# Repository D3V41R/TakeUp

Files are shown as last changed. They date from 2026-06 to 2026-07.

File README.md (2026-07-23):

# TakeUp

**TakeUp** is a custom quadrotor flight stack built from scratch: a hand-wired STM32F4 flight controller, a self-etched power distribution board, a bit-banged NRF24L01+ radio link, and a from-scratch DShot150 ESC driver. The end goal is voice-controlled flight — commands transmitted over audio instead of a stick input — with the current build flying on a manual PS5-controller-over-RF link while the audio pipeline is developed.

> **Status: in progress.** Attitude estimation, the RF link, and standard PWM motor control are working. DShot150 and voice control are active work-in-progress (see [Known Limitations](#known-limitations--todo)).

---

## Table of Contents

- [System Overview](#system-overview)
- [Repository Layout](#repository-layout)
- [Flight Controller (STM32F4)](#flight-controller-stm32f4)
- [IMU / Attitude Estimation (MPU6050)](#imu--attitude-estimation-mpu6050)
- [Wireless Link (NRF24L01+)](#wireless-link-nrf24l01)
- [Motor Control](#motor-control)
- [Custom DShot150 Driver](#custom-dshot150-driver)
- [Power Distribution Board](#power-distribution-board)
- [Building the Firmware](#building-the-firmware)
- [Known Limitations / TODO](#known-limitations--todo)
- [License](#license)

---

## System Overview



Today, the RC packet source is a PS5 controller relayed through an ESP32 (`Software/Src/esp32.c`) rather than voice — this is the interim control path used to validate the flight controller, IMU fusion, and radio link while the voice front-end is built out.

---

## Repository Layout

```
TakeUp/
├── Hardware/
│   └── BMS/
│       ├── DroneBMS.kicad_sch     # power distribution board schematic (KiCad 9)
│       ├── DroneBMS.kicad_pcb     # 4-layer PCB layout
│       └── PCB_Render_1.png       # 3D render
│   └── Flight Controller/
│       └── IMG_4678.jpeg          # hand-soldered flight controller build
├── Software/
│   ├── INC/                       # headers
│   │   ├── Dshot150.h
│   │   ├── Motors.h
│   │   ├── Nrf2401.h
│   │   ├── mpu6050.h
│   │   └── main.h
│   └── Src/
│       ├── Dshot150.c              # custom DShot150 frame builder + DMA-PWM transmit
│       ├── Motors.c                # standard 1000-2000us PWM ESC control
│       ├── Nrf2401.c                # bare-register NRF24L01+ driver (no external RF24 lib)
│       ├── mpu6050.c                # IMU driver + complementary filter
│       ├── esp32.c                  # ESP32 transmitter sketch (PS5 controller → NRF24)
│       └── main.c                   # flight controller entry point / RX loop
└── image.png                        # power board schematic export
```

---

## Flight Controller (STM32F4)

The flight controller runs on an STM32F4 Nucleo-64 board (pin map matches the standard Nucleo layout: `PC13` user button, `PA5` = `LD2`). Firmware is generated with STM32CubeMX/HAL and hand-extended.

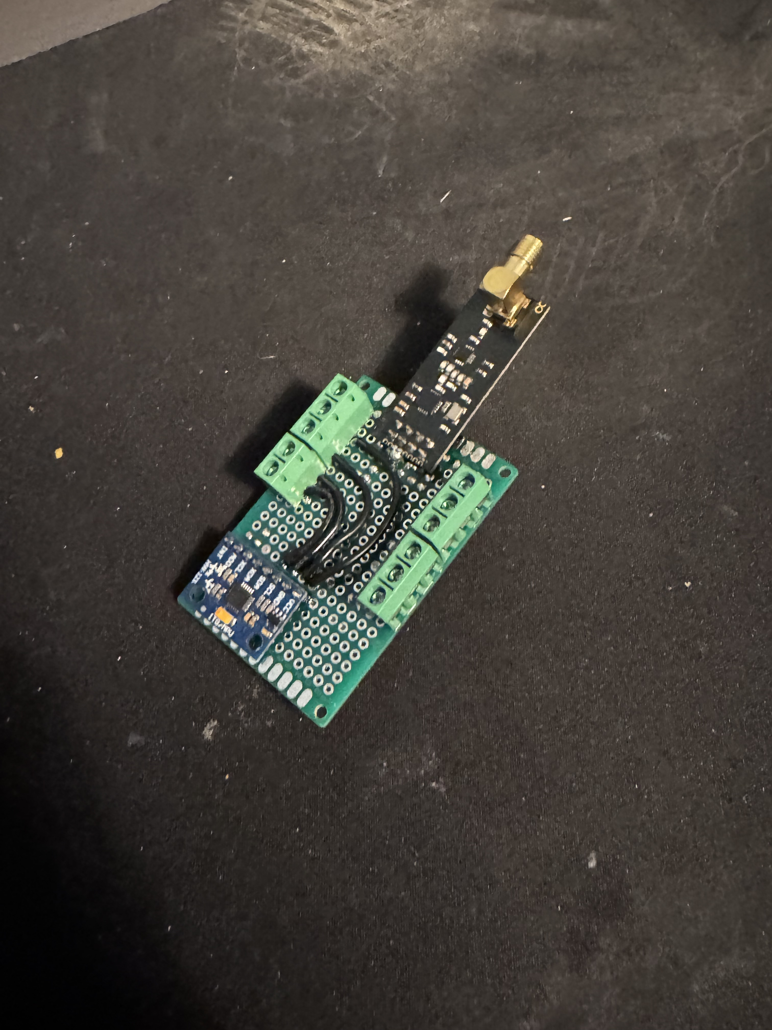
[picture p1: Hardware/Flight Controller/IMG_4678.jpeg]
Flight controller build — MPU6050 and NRF24L01+ hand-soldered onto perfboard


*Hand-wired prototype: MPU6050 breakout and NRF24L01+ (with SMA antenna) soldered onto perfboard with screw-terminal breakouts for power and signal.*

**Clock tree:** 8 MHz HSE → PLL (`M=4, N=72, P=/2`) → 72 MHz SYSCLK, APB1 = 36 MHz (72 MHz timer clock), APB2 = 72 MHz.

**Peripherals in use:**

| Peripheral | Role | Pins |
|---|---|---|
| `I2C1` | MPU6050 IMU, 100 kHz standard mode | `PB6` = SCL, `PB7` = SDA |
| `SPI2` | NRF24L01+ radio, mode 0, `fPCLK/2` | `PB14` = MISO, `PB15` = MOSI, `PC7` = SCK |
| — | NRF24 chip-select / chip-enable (bit-banged GPIO, not SPI NSS) | `PC0` = CSN, `PB0` = CE |
| `TIM2` (4ch) | ESC PWM / DShot output | `PA0` = CH1 (active), `PA1` = CH2, `PB10` = CH3, `PB2` = CH4 (configured, unused) |
| `USART2` | Debug/telemetry console, 115200 8N1 | `PA2` = TX, `PA3` = RX |

Boot sequence (`main.c`): GPIO → USART2 → I2C1 → SPI2 → TIM2 → arm ESC (`Motor_Init`) → bring up radio (`Nrf_init`) → enter RX loop, printing `BOOT`/`I2C OK`/`SPI OK`/`TIM OK` over UART at each stage so a bring-up failure is localized immediately from the serial log.

---

## IMU / Attitude Estimation (MPU6050)

`mpu6050.c` talks to the MPU6050 directly over `I2C1` (no external library) at address `0x68`.

**Init sequence:**

| Register | Value | Purpose |
|---|---|---|
| `0x75` (`WHO_AM_I`) | read, expect `0x68` | sanity check on boot |
| `0x6B` (`PWR_MGMT_1`) | `0x00` | wake from sleep, select internal clock |
| `0x1A` (`CONFIG`) | `0x01` | DLPF on, ~184 Hz bandwidth |
| `0x25` (`SMPLRT_DIV`) | `0x00` | sample rate = 1 kHz / (1 + 0) = 1 kHz |
| `0x1B` (`GYRO_CONFIG`) | `0b00011000` | ±2000 °/s full scale |
| `0x1C` (`ACCEL_CONFIG`) | `0x00` | ±16 g full scale |

Raw accel/gyro burst-reads come from `0x3B` (6 bytes, accel X/Y/Z) and `0x43` (6 bytes, gyro X/Y/Z), scaled by the datasheet sensitivity for the selected range (`/16384.0f` g/LSB for accel, `/16.4f` (°/s)/LSB for gyro).

**Gyro calibration** (`calibrate_gyro`) averages 1000 samples at boot to compute a static bias — currently computed but not yet subtracted from live readings (see [Known Limitations](#known-limitations--todo)).

**Attitude fusion** (`log_data`) runs a single-stage complementary filter:

1. Exponential low-pass (`ALPHA = 0.02`) on both accel and gyro channels.
2. Body-rate → Euler-rate transform: `phiHat_rps = gx + tan(theta)*(sin(phi)*gy + cos(phi)*gz)`, `thetaHat_rps = cos(phi)*gy - sin(phi)*gz`.
3. Gyro integration at `dt = 0.001 s` (1 kHz loop assumption) added to the running angle.
4. Fusion with accel-derived tilt (`atan`/`asin` off the gravity vector) at a 0.98 / 0.05 gyro/accel blend, printed over `USART2` as `Pitch:__, Roll:__`.

---

## Wireless Link (NRF24L01+)

Both ends of the radio link are custom drivers — the STM32 side (`Nrf2401.c`) talks directly to the NRF24L01+ command/register set over `SPI2` with no radio library, and the transmit side (`esp32.c`) uses the Arduino `RF24` library on an ESP32 paired to a PS5 controller over Bluetooth.

**Link configuration (must match on both ends):**

| Setting | Value |
|---|---|
| Data rate | 1 Mbps |
| RF channel | 85 (2.485 GHz) |
| TX power | 0 dBm |
| Address width | 5 bytes (`SETUP_AW = 0x03`) |
| RX/TX address | `E7 E7 E7 E7 E7` |
| Payload size | 16 bytes, static (no dynamic payloads) |
| Auto-ACK | disabled on both ends |
| CRC | 16-bit (ESP32 side); STM32 driver disables hardware auto-ack/CRC handling and relies on the fixed packet contract instead |

**Packet format** — a flat 16-byte struct sent as raw bytes:

```c
typedef struct {
    float throttle;
    float roll;
    float pitch;
    float yaw;
} rc_packet;   // 4 x 4-byte float = 16 bytes, matches NRF24 payload size exactly
```

**TX side** (`esp32.c`): reads PS5 gamepad stick axes via `ps5Controller`, maps left stick → throttle/roll and right stick → pitch/yaw, and pushes a packet over `RF24::write()` roughly every 20 ms.

**RX side** (`Nrf2401.c` + `main.c`): `Nrf_init()` powers up the radio, configures the RF settings above, and starts listening (`CE` high). `Recieve_nrf()` polls the `STATUS` register for the `RX_DR` flag, pulls the 16-byte payload with the `R_RX_PAYLOAD` command, and clears the flag. `main.c` copies the payload into an `rc_packet`, runs the throttle channel through a first-order low-pass (`alpha = 0.1`), and feeds the result to `Motor_SetSpeed()`.

Note: `enable_auto_ack()` exists in the driver but is not currently called from `Nrf_init()` — auto-ack stays disabled to match the transmitter's `setAutoAck(false)`.

---

## Motor Control

`Motors.c` drives ESCs with standard hobby PWM on `TIM2` channel 1: with the timer clocked at 1 MHz (72 MHz / (prescaler 71 + 1)) and a 20000-tick period, `CCR1` directly represents the pulse width in **microseconds** at a 50 Hz refresh rate — the same 1000–2000 µs framing every analog PWM ESC expects.

| Function | Behavior |
|---|---|
| `Motor_Init()` | Arms the ESC: full throttle (2000) for 2 s, then minimum (1000) for 2 s, matching the standard ESC calibration/arm beep sequence |
| `Motor_SetSpeed(percent)` | Maps 0–100 % linearly to 1000–2000 µs |
| `Motor_SetRaw(ccr)` | Direct CCR write for bench testing |
| `Motor_Stop()` | Forces minimum throttle (1000) |
| `Motor_Control_UART()` | Serial bench-test command parser (`S<pct>` set speed, `R<ccr>` set raw, `X` stop) over `USART2` |

Only `TIM2_CH1` is currently wired to a motor output in `main.c` — channels 2–4 are configured (see pin table above) but not yet driven, so multi-motor mixing isn't implemented yet.

---

## Custom DShot150 Driver

`Dshot150.c` implements the DShot150 digital ESC protocol frame-by-frame, from scratch, on top of `TIM2` + DMA.

**Frame construction is spec-correct.** A DShot frame is 16 bits: 11-bit throttle value, 1 telemetry-request bit, and a 4-bit CRC:

```c
data  = (throttle << 1) | telemetry;                  // 12 bits: 11-bit throttle + telemetry
crc   = (data ^ (data >> 4) ^ (data >> 8)) & 0xF;      // XOR-nibble checksum, per the DShot spec
frame = (data << 4) | crc;                             // final 16-bit frame
```

**Bit encoding.** Each of the 16 frame bits is expanded into a duty-cycle value for one PWM period — `170` (≈85% duty) for a `1` bit, `85` (≈42.5% duty) for a `0` bit — into a 17-entry buffer (16 bits + a trailing `0` to force the line low/reset). The buffer is streamed to `TIM2_CH1`'s `CCR1` register via `HAL_TIM_PWM_Start_DMA`, so each bit's duty cycle loads automatically without CPU intervention.

```c
void readBits(uint16_t data) {
    for (int i = 0; i < 16; i++) {
        uint16_t bitVal = (data >> (15 - i)) & 0x1;
        dshotbuffer[i] = bitVal ? 170 : 85;
    }
    dshotbuffer[16] = 0;
}
```

**Current state:** this correctly reproduces DShot's *bit encoding and checksum*, but the timer feeding it is still configured for the 20 ms / 1 MHz standard-PWM setup described above rather than a proper DShot150 bit clock (real DShot150 needs a ~6.67 µs bit period, i.e. the whole 16-bit frame takes ~107 µs — not 16 × 20 ms). Getting this fully protocol-compliant means giving `TIM2` a dedicated ARR/prescaler for DShot bit timing (or moving DShot to its own timer) and reworking the DMA burst length accordingly. This is the main piece marked "in progress" in this repo — see below.

---

## Power Distribution Board

`Hardware/BMS/DroneBMS.kicad_sch` — titled **"TakeUp Power Distribution Board"** in the schematic sheet — is a custom 4-layer (1.6 mm) PCB that takes a 3S LiPo in over an XT60 connector and produces the regulated rails and battery telemetry the flight controller needs. It's referred to informally as the "BMS" but its scope today is power conditioning + voltage sensing rather than active cell balancing.

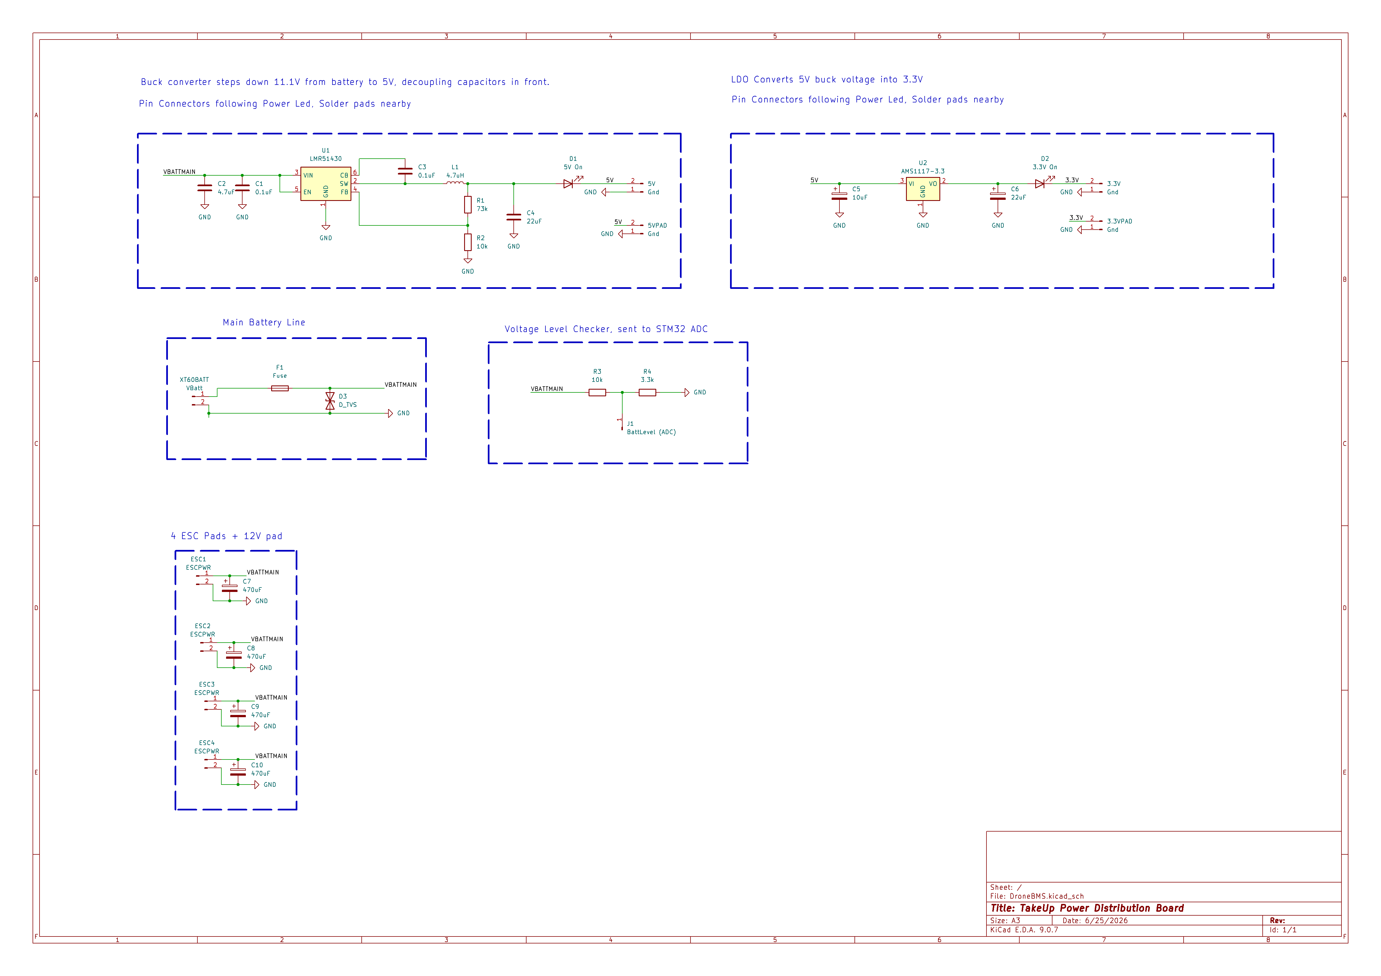
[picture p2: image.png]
BMS schematic


**Power path:**

```
XT60 (3S, ~11.1V) → Fuse (F1) + TVS diode (D3, SMAJ15A) → VBATTMAIN
                                                              │
                              ┌───────────────────────────────┼───────────────────────────────┐
                              ▼                                ▼                               ▼
                    LMR51430 buck (U1)                4x ESC power pads                Battery-voltage
                    11.1V → 5V, 4.7uH inductor,        (raw VBATTMAIN + GND,            sense divider
                    73k/10k feedback divider           470uF bulk cap each)             (10k/3.3k → STM32 ADC)
                              │
                              ▼
                    AMS1117-3.3 LDO (U2)
                    5V → 3.3V logic rail
```

| Section | Components | Notes |
|---|---|---|
| Battery input | `XT60BATT1`, `F1` (fuse), `D3` (SMAJ15A TVS) | Overcurrent + transient surge protection on the main battery line before it fans out |
| 5V rail | `U1` LMR51430 synchronous buck, `L1` 4.7 µH, `R1`/`R2` = 73k/10k feedback, bulk + decoupling caps, `D1` "5V On" LED | Steps 11.1V pack voltage down to 5V |
| 3.3V rail | `U2` AMS1117-3.3 LDO, `D2` "3.3V On" LED | Steps 5V down to 3.3V for the MCU/logic |
| Battery sense | `R3`/`R4` = 10k/3.3k divider → `J1`/`J2` | Scales VBATTMAIN down into ADC range for the STM32 to read pack voltage in software |
| ESC power | `ESC1`–`ESC4` pads, 470 µF bulk cap each, plus a raw +12V pad | Distributes unregulated battery voltage directly to each ESC |

Board: 4 copper layers (`F.Cu`/`In1.Cu`/`In2.Cu`/`B.Cu`), 1.6 mm stack-up, 4 mounting holes, KiCad 9 source files included for both schematic and layout, plus a 3D render at `Hardware/BMS/PCB_Render_1.png`.

---

## Building the Firmware

The `Software/` tree is a standard STM32CubeIDE / STM32CubeMX HAL project targeting an STM32F4 Nucleo-64 board.

1. Import `Software/` into STM32CubeIDE (or point a Makefile-based ARM GCC toolchain at `Software/INC` and `Software/Src`).
2. Flash over the Nucleo's onboard ST-LINK.
3. Open a serial terminal at 115200 8N1 on the ST-LINK VCP to watch boot status (`BOOT`, `I2C OK`, `SPI OK`, `TIM OK`) and the live RC/attitude log.
4. Flash `Software/Src/esp32.c` to an ESP32 (Arduino core, `RF24` + `ps5Controller` libraries) to act as the transmitter, or drive `TIM2_CH1` directly via `Motor_Control_UART()` for a bench test with no radio at all.

---

## Known Limitations / TODO

- **Voice control isn't implemented yet.** The current transmit path is a PS5 controller relayed through an ESP32, standing in for the audio pipeline this project is ultimately meant to use.
- **Power board has no active cell balancing/protection IC** — today it's fusing, a TVS clamp, regulation, and voltage-divider telemetry, not a full smart BMS.

---

## License

MIT — see [LICENSE](LICENSE).

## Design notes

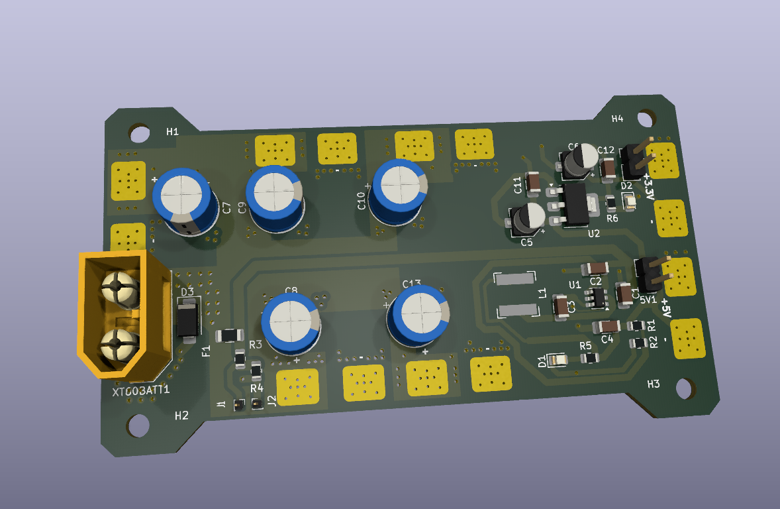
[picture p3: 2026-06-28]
Hardware/BMS/PCB_Render_1.png

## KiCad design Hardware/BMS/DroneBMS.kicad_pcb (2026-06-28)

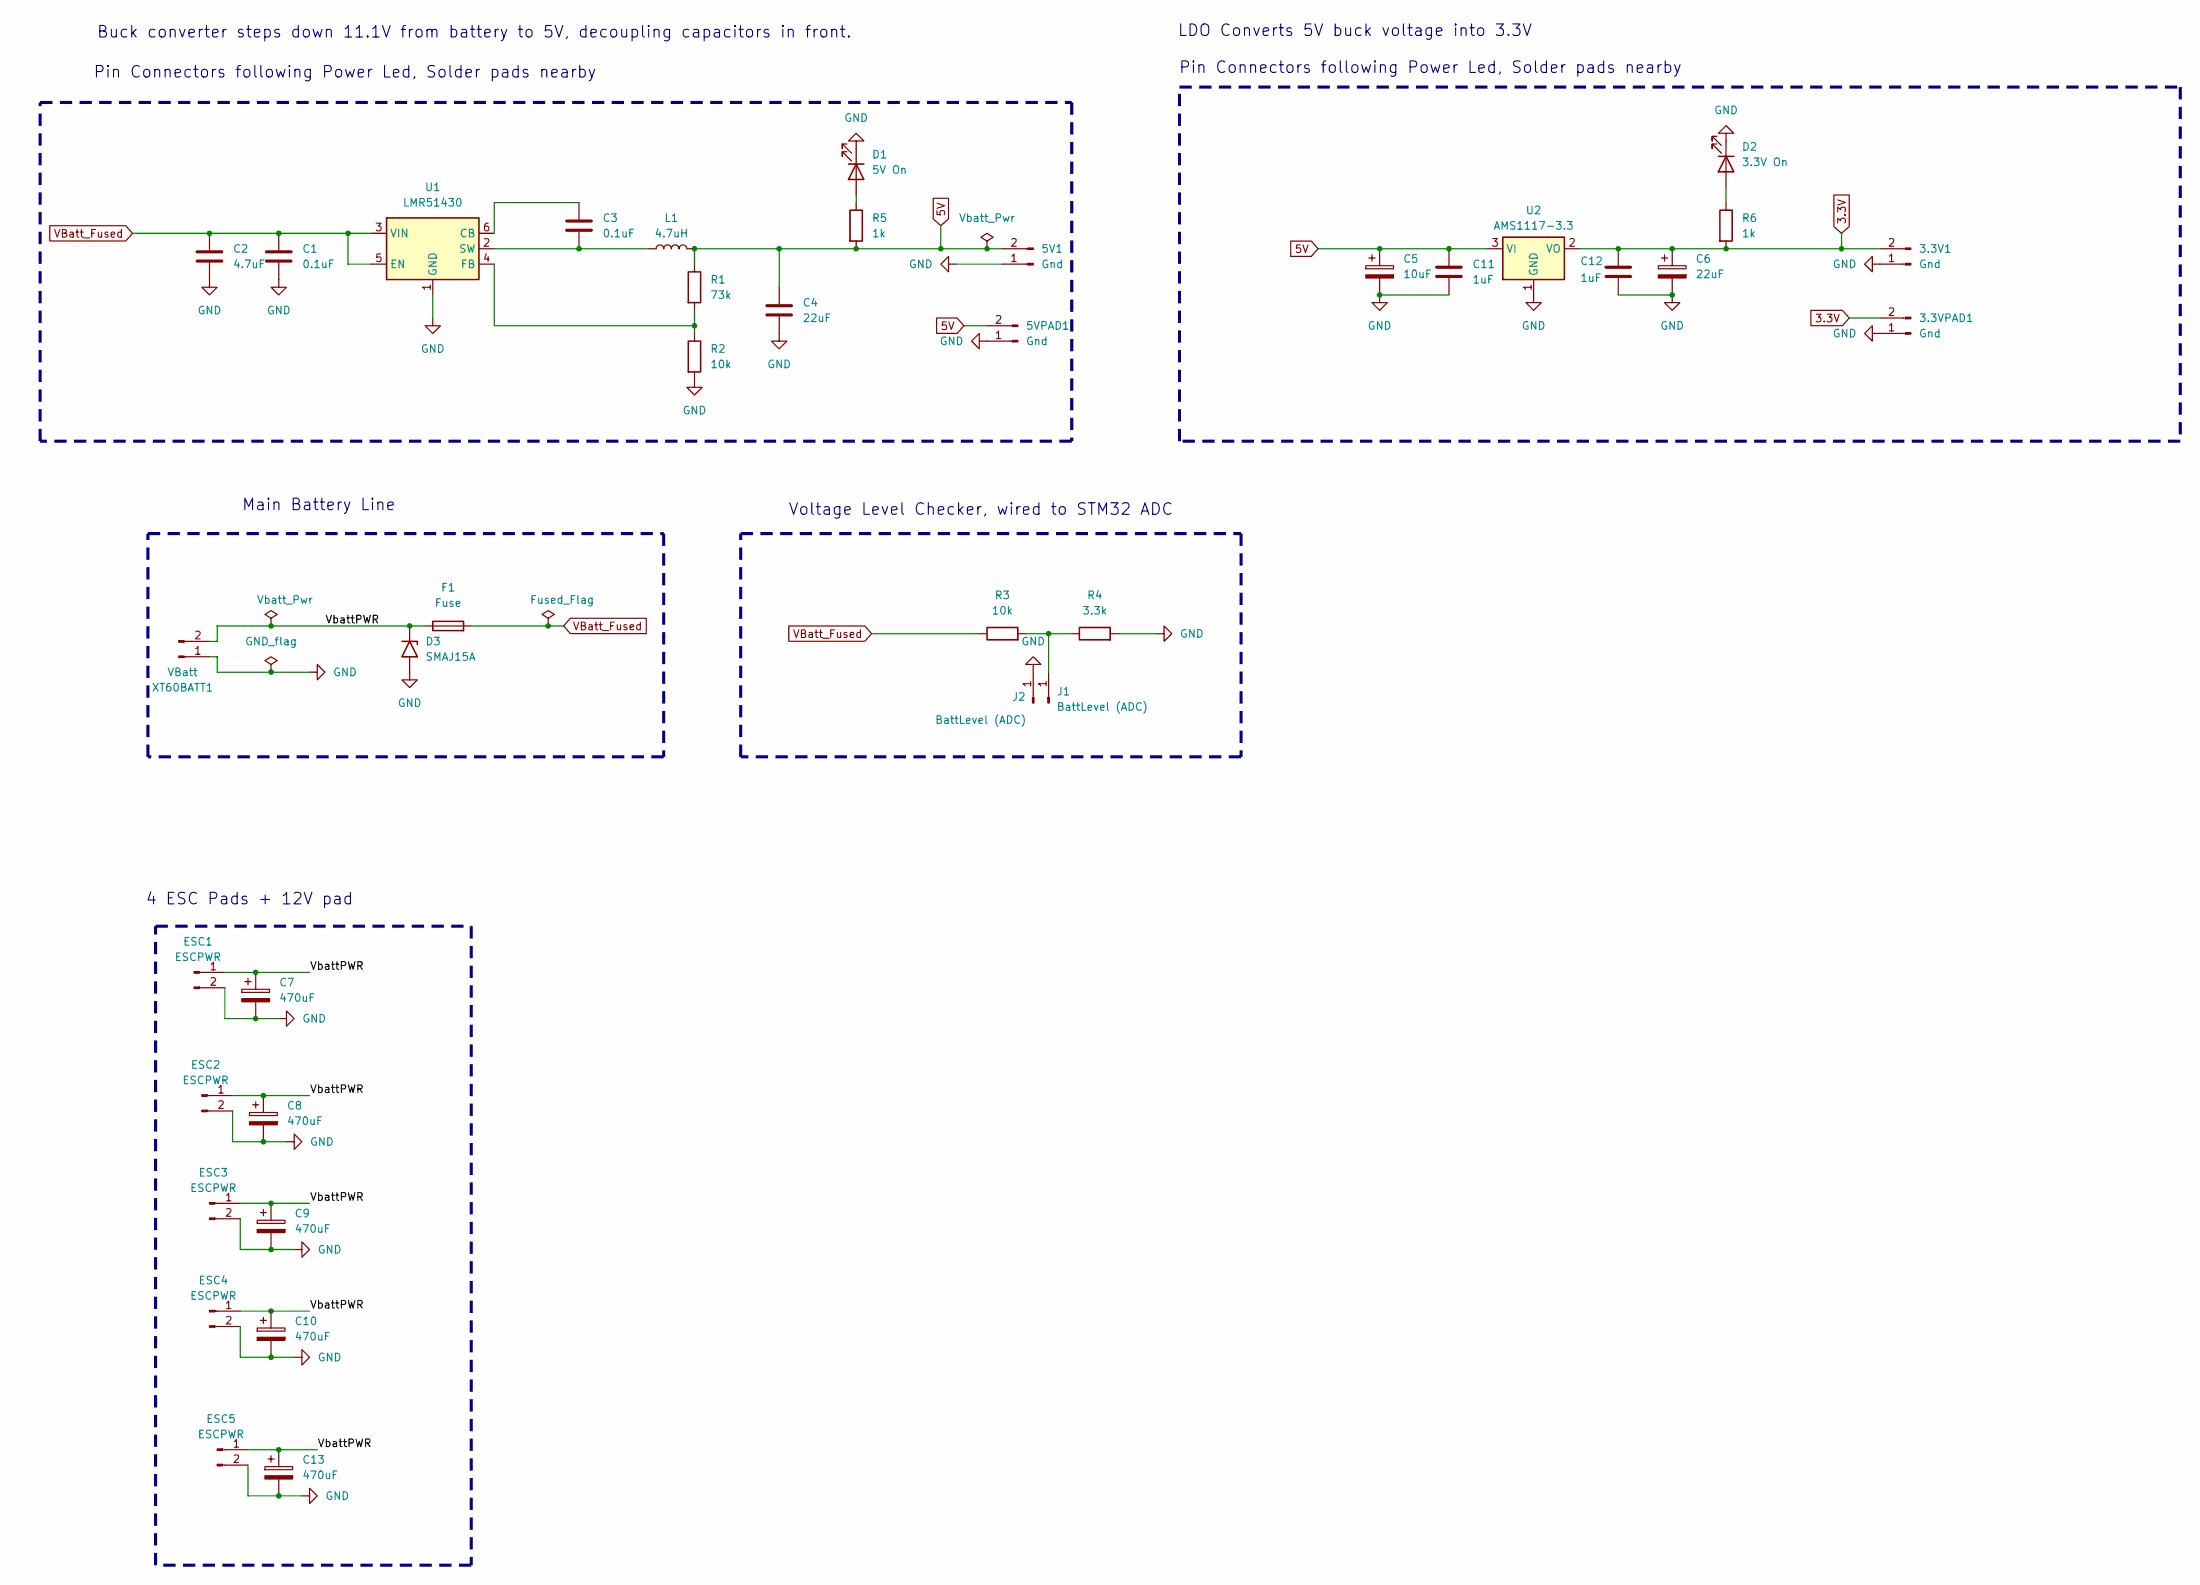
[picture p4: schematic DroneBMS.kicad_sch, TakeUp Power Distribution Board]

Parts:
3.3V1, 5V1: Gnd; PinHeader_1x02_P2.54mm_Vertical
3.3VPAD1, 5VPAD1: Gnd; ESC_SOLDER_PAD
C1, C3: 0.1uF; C_1206_3216Metric
C2: 4.7uF; C_1206_3216Metric
C4: 22uF; C_1206_3216Metric
C5: 10uF; CP_Elec_4x4.5
C6: 22uF; CP_Elec_4x5.3
C7, C8, C9, C10, C13: 470uF; CP_Radial_D8.0mm_P3.50mm
C11, C12: 1uF; C_1206_3216Metric
D1: 5V On; LED_0805_2012Metric
D2: 3.3V On; LED_0805_2012Metric
D3: SMAJ15A; D_SMA
ESC1, ESC2, ESC3, ESC4, ESC5: ESCPWR; ESC_SOLDER_PAD
F1: Fuse; Fuse_1206_3216Metric
J1, J2: BattLevel (ADC); PinHeader_1x01_P1.00mm_Vertical
L1: 4.7uH; IND_VSAB0630-4R7M
R1: 73k; R_0805_2012Metric
R2, R3: 10k; R_0805_2012Metric
R4: 3.3k; R_0805_2012Metric
R5, R6: 1k; R_0805_2012Metric
U1: LMR51430; SOT-23-6
U2: AMS1117-3.3; SOT-223-3_TabPin2
XT60BATT1: VBatt; AMASS_XT60-M_1x02_P7.20mm_Vertical

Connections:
3.3V: 3.3V1.2, 3.3VPAD1.2, C6.1, C12.1, R6.2, U2.2 (VO)
5V: 5V1.2, 5VPAD1.2, C4.1, C5.1, C11.1, L1.2, R1.1, R5.2, U2.3 (VI)
/VbattPWR: C7.1, C8.1, C9.1, C10.1, C13.1, D3.1 (A1), ESC1.1, ESC2.1, ESC3.1, ESC4.1, ESC5.1, F1.1, XT60BATT1.2
GND: 3.3V1.1, 3.3VPAD1.1, 5V1.1, 5VPAD1.1, C1.2, C2.2, C4.2, C5.2, C6.2, C7.2, C8.2, C9.2, C10.2, C11.2, C12.2, C13.2, D1.1 (K), D2.1 (K), D3.2 (A2), ESC1.2, ESC2.2, ESC3.2, ESC4.2, ESC5.2, J2.1, R2.2, R4.2, U1.1 (GND), U2.1 (GND), XT60BATT1.1
unnamed: D1.2 (A), R5.1
unnamed: D2.2 (A), R6.1
unnamed: J1.1, R3.2, R4.1
unnamed: C3.1, U1.6 (CB)
unnamed: R1.2, R2.1, U1.4 (FB)
unnamed: C3.2, L1.1, U1.2 (SW)
VBatt_Fused: C1.1, C2.1, F1.2, R3.1, U1.3 (VIN), U1.5 (EN)

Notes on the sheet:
Voltage Level Checker, wired to STM32 ADC
Buck converter steps down 11.1V from battery to 5V, decoupling capacitors in front.
LDO Converts 5V buck voltage into 3.3V
Pin Connectors following Power Led, Solder pads nearby
Main Battery Line
4 ESC Pads + 12V pad

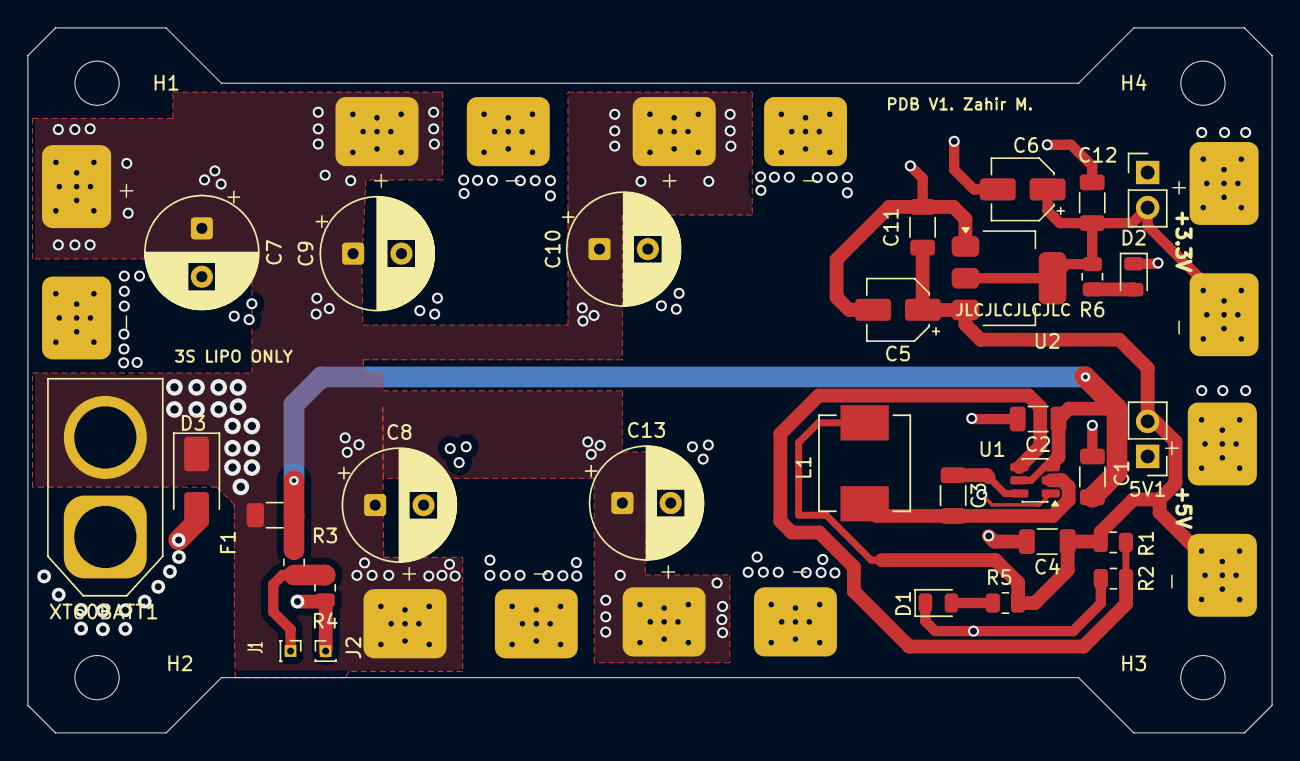
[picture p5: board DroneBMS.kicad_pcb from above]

Board: 4 copper layers, 90.0 x 51.0 mm, 42 parts (0 on the bottom side), 11 nets.

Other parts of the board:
H1, H2, H3, H4: MountingHole_3.2mm_M3

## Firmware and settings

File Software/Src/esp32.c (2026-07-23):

#include <stdint.h>
#include <stdio.h>
#include <ps5Controller.h>
#include <SPI.h>
#include <RF24.h>

#define CE_PIN  4
#define CSN_PIN 5

RF24 radio(CE_PIN, CSN_PIN);

// Must match STM32 RX address
const uint8_t address[5] = {0xE7, 0xE7, 0xE7, 0xE7, 0xE7};

typedef struct {
    float throttle;
    float roll;
    float pitch;
    float yaw;
} rc_packet;

rc_packet packet;
unsigned long lastTimeStamp = 0;

void sendPacket()
{
    bool sent = radio.write(&packet, sizeof(rc_packet));

    if (sent) {
        Serial.printf("sent OK T=%.2f R=%.2f P=%.2f Y=%.2f\r\n",
                      packet.throttle,
                      packet.roll,
                      packet.pitch,
                      packet.yaw);
    } else {
        Serial.println("sent FAIL");
    }
}

void notify()
{
    packet.throttle = -(ps5.lx / 128.0f);
    packet.yaw      =  (ps5.ry / 128.0f);
    packet.pitch    = -(ps5.rx / 128.0f);
    packet.roll     =  (ps5.ly / 128.0f);
}
void onConnect()
{
    Serial.println("Connected!");
}

void onDisConnect()
{
    Serial.println("Disconnected!");
}

void setup()
{
    Serial.begin(115200);
    delay(1000);

    if (!radio.begin()) {
        Serial.println("NRF not responding");
        while (1) {
            delay(1000);
        }
    }

    delay(100);

    radio.setChannel(85);
    radio.setDataRate(RF24_1MBPS);
    radio.setPALevel(RF24_PA_LOW);
    radio.setAutoAck(false);
    radio.disableDynamicPayloads();
    radio.setPayloadSize(16);
    radio.setCRCLength(RF24_CRC_16);
    radio.openWritingPipe(address);
    radio.stopListening();

    radio.flush_tx();
    radio.printDetails();
    Serial.print("Payload size ");
    Serial.println(sizeof(rc_packet));

    ps5.attach(notify);
    ps5.attachOnConnect(onConnect);
    ps5.attachOnDisconnect(onDisConnect);
    ps5.begin("24:A6:FA:1C:06:E9");

    Serial.println("Ready.");

    while (ps5.isConnected() == false) {
        Serial.println("PS5 controller not found");
        delay(300);
    }
}

void loop()
{
    if (ps5.isConnected()) {
        packet.throttle = -(ps5.lx / 128.0f);
        packet.yaw      =  (ps5.ry / 128.0f);
        packet.pitch    = -(ps5.rx / 128.0f);
        packet.roll     =  (ps5.ly / 128.0f);

        bool sent = radio.write(&packet, sizeof(rc_packet));

        Serial.printf("sent %s T=%.2f R=%.2f P=%.2f Y=%.2f\r\n",
                      sent ? "OK" : "FAIL",
                      packet.throttle,
                      packet.roll,
                      packet.pitch,
                      packet.yaw);

        delay(20);
    }
}

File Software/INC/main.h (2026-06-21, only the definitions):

#define B1_Pin GPIO_PIN_13
#define B1_GPIO_Port GPIOC
#define CSN_Pin GPIO_PIN_0
#define CSN_GPIO_Port GPIOC
#define USART_TX_Pin GPIO_PIN_2
#define USART_TX_GPIO_Port GPIOA
#define USART_RX_Pin GPIO_PIN_3
#define USART_RX_GPIO_Port GPIOA
#define LD2_Pin GPIO_PIN_5
#define LD2_GPIO_Port GPIOA
#define CE_Pin GPIO_PIN_0
#define CE_GPIO_Port GPIOB
#define TMS_Pin GPIO_PIN_13
#define TMS_GPIO_Port GPIOA
#define TCK_Pin GPIO_PIN_14
#define TCK_GPIO_Port GPIOA
#define SWO_Pin GPIO_PIN_3
#define SWO_GPIO_Port GPIOB

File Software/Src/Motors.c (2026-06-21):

#include "Motors.h"



extern TIM_HandleTypeDef htim2;
extern UART_HandleTypeDef huart2;

void Motor_Init(void){	// arm ESC, wait for beeps

    HAL_TIM_PWM_Start(&htim2, TIM_CHANNEL_1);
    TIM2->CCR1 = 2000;    // full throttle
    HAL_Delay(2000);
    TIM2->CCR1 = 1000;    //minimum throttle
    HAL_Delay(2000);      // wait for beeps to finish
}


void Motor_SetSpeed(uint8_t percent){ // 0-100% mapped to 1000-2000
	uint16_t CCR = 1000 + (percent * 10);
	TIM2->CCR1 = CCR;


}


void Motor_Stop(void){
    TIM2->CCR1 = 1000;
}



void Motor_SetRaw(uint16_t ccr){
	TIM2->CCR1 = ccr;

}

void Motor_Control_UART(UART_HandleTypeDef *huart, uint8_t *buff, uint16_t len){
    HAL_UART_Receive(huart, buff, len, HAL_MAX_DELAY);
    HAL_UART_Transmit(huart, buff, len, HAL_MAX_DELAY); // echo back what you received

    if (buff[0] == 'S') {
        uint8_t percent = atoi((char*)&buff[1]);
        Motor_SetSpeed(percent);
        HAL_UART_Transmit(huart, (uint8_t*)"Speed Set\r\n", 11, HAL_MAX_DELAY);
    } else if (buff[0] == 'R') {
        uint16_t ccr = atoi((char*)&buff[1]);
        Motor_SetRaw(ccr);
        HAL_UART_Transmit(huart, (uint8_t*)"Raw Set\r\n", 9, HAL_MAX_DELAY);
    } else if (buff[0] == 'X') {
        Motor_Stop();
        HAL_UART_Transmit(huart, (uint8_t*)"Stopped\r\n", 9, HAL_MAX_DELAY);
    } else {
        HAL_UART_Transmit(huart, (uint8_t*)"Unknown CMD\r\n", 13, HAL_MAX_DELAY);
    }
}

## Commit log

2026-06-12 Added Software files for Mpu sensor calibration
    * Implemented Complimentary filter to determine accurate Roll / Pitch Angles
2026-06-21 Added Motor Control, RF Recieving And Transmission, Filtered Motor Control
    *Added configurable Motor control Via Tim2 Peripheral
    * Added NRF recieving and transmission on dedicated address
    * Configured and tested drone Payload for Roll / Pitch / Yaw / Throttle
2026-06-23 Added Esp32 Transmitter Code
2026-06-25 Added Kicad Schematic
2026-06-28 Added BMS Design Files
    [DroneBMS.kicad_pcb, DroneBMS.kicad_sch]
2026-06-28 Updated Pcb Footprints
    [DroneBMS.kicad_pcb, DroneBMS.kicad_sch]
2026-07-09 Update README with BMS schematic and project status
    Added a section for BMS schematic and updated project status.
2026-07-22 Added Custom Dshot 150 Driver.c
2026-07-23 Updated ReadMe with current project status.

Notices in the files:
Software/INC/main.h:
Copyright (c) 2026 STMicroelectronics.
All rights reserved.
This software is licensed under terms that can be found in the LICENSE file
